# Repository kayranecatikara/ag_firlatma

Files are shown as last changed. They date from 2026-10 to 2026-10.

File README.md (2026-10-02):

# Ağ Fırlatma Mekanizması — Tasarım, Modelleme ve Doğrulama

Tail-sitter VTOL dronun altına monte edilen, **lastik bant tahrikli ağ
fırlatıcı**. Hedef: **X-UAV Talon** (1718 mm kanat açıklığı). İki araç da
**100 km/h** ile uçuyor.

**Öldürücü mekanizma pervaneye ip dolanmasıdır** — bilyeler ikincil
(12 g, 20 m/s'de 2.4 J: köpüğe çukur açar, yapı kırmaz). Tek bir ipin
pervaneye değmesi motoru durdurmaya yeter; bu, ağın göz açıklığını
belirleyen temel kriterdir.

> ⚠️ **Durum: üretime hazır, HENÜZ TEST EDİLMEDİ.** Modelin
> cevaplayamadığı üç soru var (§6) — yer testleri yapılmadan uçuşa
> geçilmemeli.

---

## 1. Nasıl geliştirildi — yöntem

**İki katmanlı modelleme.** Ucuz bir indirgenmiş model (ROM) ile tasarım
uzayı taranıyor, pahalı tam 3B model ile doğrulanıyor.
**ROM defalarca YANLIŞ tasarım kararı üretti** — "yay uygulanamaz",
"helisel yiv gereksiz" gibi sonuçların hepsi ROM artefaktıydı ve ancak tam
model + Monte Carlo ile yakalandı (§5).

**SciPy ile tasarım uzayı keşfi.** Sobol dizisiyle örnekleme,
`differential_evolution` ile optimizasyon, Spearman sıra korelasyonuyla
duyarlılık analizi.

**Ağ modeli.** Yığınsal parametre (lumped-parameter) yaklaşımı: ağ
düğümlere yığınlaştırılıyor, iplikler **yalnızca ÇEKME taşıyan**
viskoelastik elemanlar — basma kuvveti taşımıyorlar (tek taraflı kısıt).
Bu, uzay enkazı yakalama literatürünün standardı. Her elemana
**normal/teğet ayrışımlı silindir sürüklemesi** uygulanıyor
(Cd_n ≈ 1.1, Cd_t ≈ 0.03). Entegrasyon: velocity-Verlet, CFL zaman adımı.

**Parametrik CAD.** FreeCAD 0.19 headless (`freecadcmd`), OpenCascade
boolean işlemleri. Tüm geometri `v4_konfig.json`'dan türetiliyor.

**Gazebo Harmonic (gz-sim 8) + DART, ÖZEL C++ system plugin.**
Gazebo'nun kendi sürükleme eklentileri ipliği modelleyemiyor; iplik
gerilmesi ve aerodinamik `AgFizik.cc` içinde hesaplanıp `AddWorldForce`
ile uygulanıyor.

**HİBRİT DEVİR.** Ağın paketten açılması rijit-cisim temas problemi
değildir: paketli halde 709 çarpışma küresi 16 mm'lik hazneye tıkılıdır ve
DART'ın LCP çözücüsü yüz binlerce temas kısıtıyla çöker. Çözüm:
*paketten açılma* doğrulanmış Python modelinde, *temas ve yakalama*
Gazebo'da — ağ **t = 80 ms**'de açık halde devralınıyor.

**Tedarik araştırması.** Paralel web ajanlarıyla; her link açılıp sayfa
içeriğinden doğrulandı, doğrulanamayan link verilmedi (`TEDARIK_PLANI.md`).

### Kullanılan araçlar
`Python 3` · `NumPy` · `SciPy` · `matplotlib` · `FreeCAD 0.19` ·
`Gazebo Harmonic (gz-sim 8)` · `DART` · `C++17` · `gz-plugin2` · `CMake`

---

## 2. Doğrulama — projenin güven temeli

Python (kendi yazdığım velocity-Verlet entegratörü) ve Gazebo (DART)
**bağımsız iki çözücü** olarak aynı fiziği çözüyor:

| | Python | Gazebo | sapma |
|---|---|---|---|
| R_tepe | 1.126 m | 1.120 m | **−0.5 %** |
| zirve zamanı | 192 ms | 192 ms | **−0.2 %** |
| atış penceresi | 3.54 – 6.08 m | 3.54 – 6.04 m | **4 cm** |

Gerçek altıgen örgüde, devir sonrası serbest uçuşta sapma **%0.23**.

**Bağımsız bir teyit daha:** ürettiğim örgü **83.2 m** iplik veriyor,
`params.py`'daki analitik formül (`2A/göz + 6R`) **81.1 m** — **%2.5**
uyum. İki ayrı yoldan hesaplanan büyüklükler örtüşüyor.

---

## 3. Sonuçlar

```
çıkış hızı        : 31.1 m/s
açılma            : 200 ms'de R = 1.13 m      (gereken 0.859 m — Talon yarı açıklığı)
geometrik pencere : 3.56 – 6.54 m
EN İYİ TETİKLEME  : 4.0 – 4.5 m               (§5 — Gazebo bunu tersine çevirdi)
ip tepe yükü      : 19 N                      (kopan eleman: 0)
sistem kütlesi    : ~390 g
ağ                : Ø2.6 m altıgen dış hat, KARE göz 200 mm,
                    142 bağ, ~2.5 saat el emeği
```

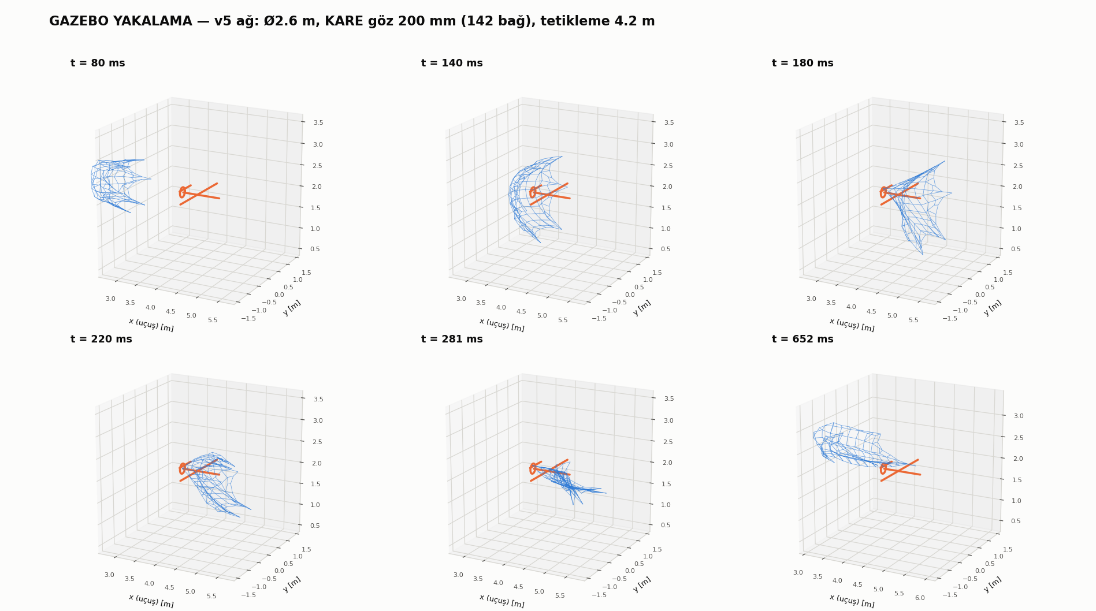
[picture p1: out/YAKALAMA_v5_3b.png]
Yakalama


### Tasarım tablosu

| | Değer |
|---|---|
| Namlu | Ø52 × **149.8 mm**, DÜZ delik (yiv yok), arkası açık (yükleme ağzı) |
| Tahrik | **4 × Ø15.2/4 mm saf lateks tüp**, **30.3 mm** kauçuk boyu, ×4.0 kurulu |
| Bant bağlantısı | ağız bileziği kulakları (±Z) → kapsüldeki **Ø8 civa çeliği** çapraz pim (düz yarıklardan çıkar) |
| Yuva koni açısı | **13°** |
| Bilye / ağ | Ø12.7 **kurşun** × 6 / **Ø2.6 m, KARE göz 200 mm** + çevre halatı, Dyneema **örgü** Ø0.165 |
| Strok | **91 mm** |
| v_çıkış | **31.1 m/s** |
| Atış penceresi | **3.56 – 6.54 m** geometrik · **EN İYİ 4.0–4.5 m** (bkz. §5) |
| Kütle | **~390 g** (servolar + ağ + bilyeler dahil) — MG996R ile 492 g idi |
| Tetik | 2 karşılıklı pim, kapaklı kartuş + geri-getirme yayı; **PTFE burç ŞART**; 2 × **MİKRO** metal dişli servo (~14 g), makara r=2.2 mm |

Yaylı tasarım `cad/eski_tasarimlar/yay_tahrikli/` altında arşivlendi (kısa namluda
blok boyu stroku yiyor, kurma kuvveti 1000 N'u aşıyordu).

Bant doğrulaması: tek banda bagaj kantarıyla ×3.0'da ~184 N, ×3.5'te ~217 N
beklenir (`agsim/lastik.py: cekme_testi_tablosu`). Ölçüm farklıysa `Gmod`'u
aynı oranda düzeltin.

---

## 4. Temel fizik

**Balistik uzunluk** λ = 2m/(ρ·Cd·A) — ağ menzilini belirleyen tek baskın
parametre. Kapalı form erişilebilir menzil:

```
Δx_max = λ·[ln(v₀/V) − 1 + V/v₀],     v₀ = V + v_namlu
```

**Ağı durduran sürüklemedir, gerilme değil.** Tepe iplik gerilmesi
serbest uçuşta 2–4 N, kopma yükü 64 N. Ağ gergin hale gelip durmuyor;
hava onu yavaşlatıyor.

**Ağ neden açıldıktan sonra kapanıyor?** Bilyeler radyal hızla dışa
açılıyor, ağ gerilince elastik olarak geri çekiyor; hava bu salınımı
sönümlüyor. İplik sönümlemesinin (ζ = 0.05…0.90) etkisi **sıfır** —
sönümleme tamamen aerodinamik.

**Ağır bilye hafif ağı çekiyor.** Bilye λ ≈ 234 m, ağ λ ≈ 0.24 m.

**Pervane yakalama kriteri.** Kenarı `a` olan kare hücreye sığan en büyük
çember `a√2`. Eskiden "diskte bir DÜĞÜM bulunsun" diyordum (göz < 163 mm);
tek ip motoru durdurmaya yettiği için gerçek kriter "diski en az bir İP
kessin" → **göz < 230 mm**. Göz 200 mm seçildi (%13 pay).
Gazebo ölçümü: ağ uçağın üzerinden süpürülürken diskten **32 farklı
iplik** geçiyor.

---

## 5. Yol boyunca düzeltilen hatalar

> Bu bölüm projenin en değerli kısmı. "Şunu yaptık, çalıştı" tarzı bir
> anlatım bu projeyi anlatmaz — doğru sonuçların çoğuna yanlış sonuçları
> yakalayarak varıldı.

### Fizik / model
- **Hava sürüklemesinin etkisini küçümsemiştim.** Kullanıcı itiraz etti,
  kontrol ettim: **HAKLIYDI.** Menzil vakumda 61.6 m, sürüklemeyle 4.0 m.
  Yaptığım karşılaştırma zaten ikisi de sürükleme-baskın iki durumu
  kıyaslıyordu, bu yüzden etki küçük görünüyordu.
- **"Helisel yiv gereksiz" bulgusu YANLIŞTI.** Enerjisi yetersiz yay ve
  yanlış amaç fonksiyonundan geliyordu; Pareto cephesinde 9 tasarımın
  8'i helisel yiv kullanıyordu.
- **"Yay uygulanamaz" sonucu ROM artefaktıydı.** Tam model Monte
  Carlo'da %93–98 yakalama verdi.
- **Amaç fonksiyonu yanlıştı** (R_eff). `differential_evolution`
  11.27 m'lik sahte bir optimum buldu; Monte Carlo o tasarımda **%0**
  yakalama verdi. Amaç fonksiyonu "angajman anındaki kapsama"ya çevrildi.
- **netfull'de sürükleme gerçek ağa ölçeklenmiyordu.** Kütle
  ölçekleniyordu ama sürükleme ölçeklenmiyordu → ağ sürüklemesi **~2.5×
  düşük** hesaplanıyordu. Bu düzeltmeden önceki tüm sayılar iyimserdi.
- **Kare-göz iplik formülü altıgen ağa uygulanmıştı.**

### Topoloji — en büyük düzeltme zinciri
- **Tasarım taraması "örümcek ağı" topolojisiyle yapılmıştı.** Gerçek
  altıgen örgü **%6.7 daha geniş** açılıyor. Sebep topolojik: örümcek
  ağındaki sürekli çevrel halkalar çember gerilmesiyle açılmaya direniyor,
  bal peteğinde sürekli halka yok.
- **ÇEVRE HALATI modellenmemişti** — malzeme listesinde (F2) vardı ama
  simülasyona girmemişti. Onsuz kare ağın köşeleri desteksiz kalıyor ve
  açılamıyordu; bu yüzden kare gözü yanlış değerlendirdim.
- **Düğüm sayısını 709 sandım; gerçek 315.** Malzeme listesindeki 259
  (göz kesişimi) doğruymuş. Kendi kurduğum altıgen kafesin düğümünü sayıp
  listeyi "düzeltmiştim".

### Operasyonel — Gazebo'nun tersine çevirdiği tavsiye
**"Pencerenin uzak yarısından ateşle, ip yükü düşük olur" demiştim. YANLIŞ.**

Python modeli yalnızca *"ağ yeterince açık mı"* diye bakıyor;
*yakalayıp yakalamadığına* bakmıyor. Gazebo'nun temas simülasyonu uzakta
ağın uçağın üzerinden **değip geçtiğini** gösterdi:

| tetikleme | ağın uçağa serilme oranı | aktarılan momentum |
|---|---|---|
| 3.6 m | %78 | 2.08 kg·m/s |
| **4.2 m** | %52 | 1.64 kg·m/s |
| 5.0 m | %28 | 0.64 kg·m/s |
| 7.0 m | **%24** | 0.37 kg·m/s |

**DOĞRUSU: 4.0 – 4.5 m'den ateşle.**

### Gazebo / yazılım
- **Ağ düğümlerinin pozları mutlak yazılıydı.** Entegrasyon risk analizinde
  yakalandı: fırlatıcı başka bir yere konduğunda ağ ondan kopuk, yanlış bir
  ofsette taşınıyordu — doğru yönde ama yanlış yerden çıkan, sessiz bir hata.
  Plugin'e `<uretim_firlatici_poz>` eklendi; ağ artık fırlatıcının gerçek
  pozuna taşınıyor.
- **Hedef link adı `govde` çok yaygındı.** Entegrasyon testinde plugin,
  test dronunun kendi gövdesini hedef sanıp üzerine trim kuvveti uyguladı.
  Hedef link `talon_govde` olarak yeniden adlandırıldı.
- **`WorldPoseCmd` kaldırma zamanlaması.** Kinematik taşımayı eklerken poz
  komutunu atıştan bir adım sonra kaldırıyordum; ateşleme adımında poz komutu
  ile hız komutu çakışıp **sahte gerilme sıçraması** yarattı (16 → 31 N).
  Entegrasyon testinde yakalandı; komut artık ateşleme adımında, hızlar
  verilmeden önce kaldırılıyor.
- **`SetLinearVelocity` kalıcı bir KİNEMATİK KISIT bırakıyor.**
  `LinearVelocityCmd` bileşeni her adımda yeniden uygulanıyor → gövdeler
  o hıza kilitleniyor ve hiçbir kuvvete tepki vermiyor. Serbest düşme
  testiyle kanıtlandı (hız −0.006 m/s'de sabit kaldı, −2.0 olmalıydı).
  Atıştan bir adım sonra komut kaldırılarak düzeltildi.
- **dt kararlı sınırın 4 katıydı** (0.5 ms, sınır 0.12 ms) → sayısal
  patlama, ODE AABB taşması. Artık dt iplik periyodundan otomatik
  türetiliyor.
- **Kuvvet tavanı 5 N çarpma anında 10486 kez devreye girip fiziği
  bozuyordu.** 200 N'a çekildi (yalnızca NaN koruması); yerine iplik
  kopma sayacı eklendi.
- **SDF üreticisinde tanımsız sabit** (`PERVANE`) → üretim sessizce
  çöktü ve **4 Gazebo koşusu ESKİ dünya dosyasını** simüle etti.
  Dördünün de birebir aynı sayıyı vermesi fark ettirdi. Üretici hatası
  artık koşuyu durduruyor.
- **Hazne hacmi eski Python değerinden alınmıştı** (20.5 cm³);
  CAD'deki gerçek değer **17.3 cm³**.

### CAD
- v1'de durdurma omzu bilyeleri engelliyordu (omuz iç çapı 18.7 mm,
  bilye dış kenarı 19.9 mm).
- Kama/oluk profilinin eksenleri ters girilmişti (radyal ↔ çevrel).
- Pim kapsüle teğetti → geçersiz katı; profil 0.8 mm gömüldü.
- **Tetik tek geçme çubuktu.** Kullanıcı asimetrik çekiş itirazı yaptı:
  **HAKLIYDI.** İki ayrı pime bölündü.

### Namlu kısaltma — menzil beklenenden az etkilendi
Namlu 180.5 → **149.8 mm**'ye indirildi (strok 114 → 91 mm).

| namlu | strok | enerji | v_çıkış | pencere |
|---|---|---|---|---|
| 180.5 mm | 114 mm | 78.2 J | 34.6 m/s | 3.58 – 6.80 m |
| **149.8 mm** | **91 mm** | **62.4 J** | **31.1 m/s** | **3.56 – 6.54 m** |
| 140 mm | 84 mm | 57.3 J | 29.9 m/s | 3.56 – 6.46 m |

Çıkış hızından **%10** verildi ama pencerenin uzak kenarı sadece **26 cm**
kısaldı. Sebep §4'teki balistik uzunluk: ağı durduran sürüklemedir ve
`Δx ∝ λ·[ln(v₀/V) − 1 + V/v₀]` — **logaritmik**, hıza doymuş davranır.
Kazanç: namlu −31 mm, **−20 g**, filament 210 → 190 g.
Kurma kuvveti **değişmedi** (30.6 kg/bant) çünkü λ=4.0 korundu; sadece
bant daha kısa kesiliyor (38 → 30.3 mm).

Gazebo ile doğrulandı (tetikleme 4.2 m): tepe iplik yükü **16.4 N**,
kopan eleman **0**, pervaneden geçen **14 iplik**, ağın uçağa serilme
oranı **%47**, aktarılan momentum **1.30 kg·m/s**. Yakalama 180 mm'ye
göre bir miktar zayıfladı (53 → 14 iplik, momentum 1.64 → 1.30) ama
"tek ip yeter" kriterinin **14 katı** üzerinde.

### Tedarik — araştırmanın değiştirdiği tasarım kararları
- **7075-T6 Ø8 Türkiye'de SATILMIYOR** (çekme 7075 Ø13'ten başlıyor).
  Mukavemet hesabı yapıldı: tasarım gerilmesi **202 MPa**.

  | malzeme | SF | karar |
  |---|---|---|
  | 7075-T6 *(hedef)* | 2.4× | TR'de yok |
  | **civa çeliği 1.2210** | **2.2×** | ✅ seçildi |
  | 6061-T6 | 1.4× | sınırda |
  | 6063 | **0.84×** | ❌ kırılır |
  | 304 paslanmaz | **1.04×** | ❌ yetersiz |

  Bedeli: +23 g (sistem 469 → 492 g).
- **TR'deki MG996R'lerin hepsi "half metal"** (iç dişliler plastik).
  Pahalı servo almak yerine makara küçültüldü — ama asıl düzeltme aşağıda.
- **MG996R çok ağırdı (110 g = sistemin %22'si).** Servo seçimini
  **iş korunumunu** gözden kaçırarak yapmıştım: `tork × açı = F_pim × strok`
  sabittir ve r=4 mm makara servonun dönüş aralığının yalnızca **86°**'sini
  kullanıyordu. Makara r=2.2 mm + kanal derinliği 5→4 mm ile **130°**
  kullanılıyor, gereken tork **3.9 → 2.15 kg·cm**'ye düşüyor.
  Sonuç: 2 × MG996R (110 g) yerine 2 × mikro metal dişli servo (28 g),
  **1.81× pay** ve **−82 g**. Namlunun servo yatağı zaten M2/mikro servo
  için tasarlanmıştı; sadece delik aralığı 18 → 28 mm'ye düzeltildi (oval,
  marka farkını tolere etsin diye).

### Üç ayrı yerde kullanıcının fiziksel sezgisi analizi yendi
1. **Sürükleme büyüklüğü** — "bu etki çok daha fazla olmalı" dedi, haklıydı.
2. **Tek pim asimetrisi** — "kapsül pimin çekildiği tarafa kayar" dedi,
   haklıydı; tasarım iki pime bölündü.
3. **Ağın gereğinden karmaşık olması** — "bu kadar ipe ve düğüme gerek yok,
   tek ip pervaneye yeter" dedi. Doğrulandı: bağ 811 → 142, iplik
   100 → 53 m, üstelik **pencere uzadı ve yakalama iyileşti**.

---

## 6. Modelin cevaplayamadıkları

Dürüst olmak gerekirse üç soru açık. Üçü de yer testiyle çözülecek.

**1. AĞIN DOLANMASI — en kritik belirsizlik.**
İpin ipe takılması rijit-cisim + LCP çözücüsüyle modellenemez; ip/kumaş
çözücüsü (Cosserat çubuk veya konum-tabanlı dinamik) gerekir. Ağ paketten
temiz açılacak mı, bunu **yalnızca yer testi** söyler (240 fps çekim,
`URETIM_MONTAJ_REHBERI.md` §T3). Üç temiz açılma görülmeden uçuşa
geçilmemeli.

**2. PERVANENİN İPİ KESME EŞİĞİ.**
Eğilim biliniyor (temas basıncı ∝ 1/d), **mutlak eşik bilinmiyor**.
Kullandığım enine dayanım verisi gerçek kesilme kriterini yakalamıyor.
Tezgâh testi gerekiyor (§T5): ipi kanada sar, ~15 N ger, motoru çalıştır.

**3. DÜĞÜM VERİMİ.**
%55 literatür tahmini (UHMWPE aralığı %50–60). Gerçek düğümlü numuneyle
çekme testi yapılmalı. *(Yükler düşük olduğu için belirleyici değil —
hiçbir eleman kapasitenin yarısına ulaşmıyor.)*

**Ayrıca: TARET TASARIMI henüz yapılmadı** (kullanıcı isteğiyle ertelendi).
Şimdilik sabit bir yatak yeterli.

---

## 7. Dosya haritası

```
baski/                  ★ 3D BASKI — doğrudan slicer'a at
                          8 × STL (BASKI YÖNÜNDE hazır, tablaya oturtulmuş,
                          döndürme gerekmez) + 8 × STEP + BASKI_AYARLARI.md
baski.zip                 aynısının zip'i

ALISVERIS.md            ★ ALIŞVERİŞE GİDERKEN BUNU AL — tek dosya,
                          siparişe göre gruplu, 42 kutucuk
URETIM_MONTAJ_REHBERI.md  üretim + montaj, 14 bölüm (güvenlik, baskı,
                          ağ örme, bant, montaj, kurma, testler)
malzeme_listesi.md        teknik özellikler, her parçanın nereye gittiği
TEDARIK_PLANI.md          doğrulanmış satın alma linkleri
SATIN_ALMA_LISTESI.md     kategori bazlı alışveriş rehberi
TORNA_IS_EMRI.png         tornacıya götürülecek ölçülü teknik resim

agsim/                    fizik modeli
  params.py                 parametreler, malzeme veritabanı
  netfull.py              ★ tam 3B ağ modeli (karar veren model)
  hexag.py                ★ gerçek örgü üreteci (altıgen + kare + çevre halatı)
  lastik.py               ★ lateks bant modeli (neo-Hooke)
  kesilme.py              ★ pervane kesme analizi (Smith, bükülme, düğüm)
  aero.py                   sürükleme
  netrom.py, dse.py, ...    ROM ve tarama altyapısı (arşiv)

cad/
  lastik_montaj_v4.py     ★ parametrik tam montaj (v4_konfig.json'dan)
  baski_parcalari.py      ★ baskı parçalarını üretir → baski/
  ciz_torna_resmi.py        torna iş emri çizimi
  eski_tasarimlar/          arşiv (.py kaynaklar; .step'ler üretilebilir)

gazebo/
  models/ag_firlatici/    ★ MONTE EDİLEBİLİR MODEL PAKETİ (bkz. §9)
                            model.config + model.sdf + meshes/
                            4 link, 389 g, montaj çerçeveleri
  plugin/AgFizik.cc       ★ özel C++ system plugin (ağ fiziği + tetik topic'i)
  scripts/ag_sdf_uret.py  ★ dünya üreteci
  scripts/model_paketi_uret.py  model paketini üretir
  worlds/ag_atis.sdf        ÜRETİLMİŞ test dünyası (monte edilecek model DEĞİL)
  worlds/ag_eklentisi.sdf ★ ÜRETİLMİŞ — kendi dünyana yapıştırılacak
                            ağ + plugin parçası (§9.2)
  scripts/karsilastir.py    Gazebo ↔ Python doğrulaması
  scripts/ciz_yakalama.py   3B yakalama görselleştirmesi
  kos.sh                    koşu betiği

out/                      grafikler, sonuç belgeleri, konfigürasyonlar
  GAZEBO_sonuc.md           Gazebo entegrasyonu sonuçları
  AG_v5_SADELESTIRME.md     ağ sadeleştirme kararı
  IP_CAPI_KARAR.md          iplik çapı kararı
arsiv_analizler/          süperseded analizler (OKUBENI.txt uyarısıyla)
```

**Nereden başlamalı:** üretecekseniz `ALISVERIS.md` → `baski/` →
`URETIM_MONTAJ_REHBERI.md`. Modeli anlamak istiyorsanız §5 (hatalar) →
`agsim/netfull.py` → `out/GAZEBO_sonuc.md`.
**Kendi dronuna entegre edecekseniz doğrudan §9.**

---

## 8. Nasıl çalıştırılır

```bash
# --- Python analizleri ---
python3 run_menzil_nihai.py        # menzil, atış penceresi, Monte Carlo
python3 run_ip_incelt.py           # iplik çapı taraması
python3 ciz_ag_2b.py               # ağ topolojisi karşılaştırma çizimi

# --- CAD ---
freecadcmd cad/lastik_montaj_v4.py # tam montaj → cad/V4_*.step
freecadcmd cad/baski_parcalari.py  # baskı parçaları → baski/ (STL + STEP)

# --- Gazebo plugin derleme ---
cd gazebo/plugin && mkdir -p build && cd build
cmake .. -DCMAKE_BUILD_TYPE=Release && make -j4

# --- Simülasyon ---
./gazebo/kos.sh dogrulama          # hızlı, hedefsiz, Python ile karşılaştırma
AG_ORGU=kare ./gazebo/kos.sh yakalama       # gerçek örgü + hedef
AG_ORGU=kare ./gazebo/kos.sh yakalama gui   # üstüne GUI

python3 gazebo/scripts/karsilastir.py       # Gazebo ↔ Python doğrulaması

# --- Monte edilebilir model paketi + harici tetikle atış (bkz. §9) ---
python3 gazebo/scripts/model_paketi_uret.py        # gazebo/models/ag_firlatici/
export GZ_SIM_RESOURCE_PATH=$PWD/gazebo/models
AG_FIRLATICI=1 AG_TETIK=harici AG_ORGU=kare AG_RAG=1.3 AG_GOZ=0.20 \
  python3 gazebo/scripts/ag_sdf_uret.py
gz sim -r gazebo/worlds/ag_atis.sdf &
gz topic -t /ag_firlatici/ates -m gz.msgs.Boolean -p "data: true"
```

### Ortam değişkenleri

| Değişken | Varsayılan | Ne yapar |
|---|---|---|
| `AG_ORGU` | `orumcek` | örgü tipi: `orumcek` \| `hex` \| `kare` |
| `AG_RAG` | config | ağ köşe yarıçapı [m] |
| `AG_GOZ` | config | göz açıklığı [m] |
| `AG_DIP` | config | iplik çapı [m] |
| `AG_MENZIL` | `4.65` | hedefin atış anındaki mesafesi [m] |
| `AG_CARPISMA` | `1` | `0` = çarpışma/hedef yok (hızlı doğrulama) |
| `AG_DEVIR` | hex/kare için `0.08` | hibrit devir anı [s]; `0` = kapsülden fırlat |
| `AG_SURE` | `0.75` | simüle edilecek sim-zamanı [s] |

### Gereksinimler
```
Python 3.8+ · numpy · scipy · matplotlib
FreeCAD 0.19+          (freecadcmd)
Gazebo Harmonic        (gz-sim 8) + gz-physics (DART)
gz-cmake3, gz-plugin2, gz-math7, gz-common5, sdformat14, CMake 3.16+
```

---

## 9. Başka bir araca entegrasyon

> Bu bölüm, fırlatıcıyı **kendi drone modeline** eklemek isteyenler için.
> `gazebo/worlds/ag_atis.sdf` bir **test dünyasıdır**, monte edilebilir model
> değildir — onu kullanma. Monte edilecek paket: `gazebo/models/ag_firlatici/`

### 9.1 Model paketi

```
gazebo/models/ag_firlatici/
  model.config          paket tanımı, kütle dağılımı, açıklama
  model.sdf             4 link + 3 eklem + 2 montaj çerçevesi
  meshes/namlu.stl      görsel (çarpışma = silindir, daha hızlı)
  meshes/kapsul.stl
```

**Eksen düzeni:** `+X` namlu ekseni (ağız yönü), `+Z` yukarı.
**Orijin:** namlunun **arka yüzünün merkezi** (yükleme ağzı).

| link | kütle | içerik |
|---|---|---|
| `namlu` | **216.2 g** | gövde + 4 lateks bant + tetik donanımı + kablolar |
| `kapsul` | **138.0 g** | kapsül + çapraz pim + **ağ + 6 kurşun bilye** |
| `servo_sag` / `servo_sol` | **14.3 g** ×2 | mikro metal dişli servo |
| **TOPLAM** | **389.4 g** | |

`kapsul` link'i `namlu`ya **prizmatik eklemle** bağlı (eksen +X, strok 0–91 mm).
Servolar sabit eklemle. Atalet tensörleri gerçek geometriden hesaplandı
(içi boş silindir / kutu).

İki montaj çerçevesi var:
- **`montaj`** — namlu ortası, üst yüzey. Kendi gövdene bağlarken bunu referans al.
- **`agiz`** — namlu ucu. **Tetikleme mesafesi buradan ölçülür.**

### 9.2 ⚠️ İKİ PARÇA GEREKİYOR — tek `<include>` yetmez

Bu en sık yapılacak hata, baştan söyleyeyim:

| | ne içerir | `<include>` ile gelir mi? |
|---|---|---|
| **1. Model paketi** `ag_firlatici` | namlu + kapsül + servolar, 389 g, montaj çerçeveleri | ✅ evet |
| **2. Ağ eklentisi** `ag_eklentisi.sdf` | **142 ağ düğümü + AgFizik plugin'i** | ❌ **HAYIR — elle yapıştır** |

**Model paketinin içinde ağ da plugin de YOKTUR** (`model.sdf`'te 0 plugin,
0 düğüm). Sadece `<include>` yaparsan: doğru kütleli, doğru görünen, ama
**hiç ateş etmeyen** bir namlu elde edersin.

Sebebi §9.6'daki ilk madde: ağ düğümlerinin her biri **ayrı `<model>`**
olmak zorunda, bu yüzden fırlatıcı modelinin *içine* konamıyorlar.

Üreteç ikinci parçayı **yapıştırmaya hazır** olarak yazıyor:
```
gazebo/worlds/ag_eklentisi.sdf    <- bunu kendi <world>'üne kopyala
```

### 9.2.1 Kendi dünyana ekleme — kopyala-yapıştır

```bash
# gz sim modeli bulsun diye:
export GZ_SIM_RESOURCE_PATH=$GZ_SIM_RESOURCE_PATH:/yol/ag_firlatma/gazebo/models
# gz sdf -k ile DOGRULAMA yapacaksan AYRICA (farkli degisken!):
export SDF_PATH=$SDF_PATH:/yol/ag_firlatma/gazebo/models
```

> ⚠️ `<include>` ve `<joint>` **DÜNYA SEVİYESİNDE** olmalı — `<model>`
> etiketinin *içine* koyup `firlatici::namlu`ya joint atarsan SDF çözemez
> (`child frame ... not found`). Aşağıdaki biçim doğrulandı.

```xml
<world name="benim_dunyam">

  <model name="benim_dronum">
    <link name="govde"> ... </link>
  </model>

  <!-- 1. PARCA: FIRLATICI MODELI — dünya seviyesinde -->
  <include>
    <uri>model://ag_firlatici</uri>
    <name>firlatici</name>
    <pose>0 0 2.0 0 0 0</pose>
  </include>

  <!-- Dünya seviyesinde sabit eklemle gövdene bağla -->
  <joint name="firlatici_baglanti" type="fixed">
    <parent>benim_dronum::govde</parent>
    <child>firlatici::namlu</child>
  </joint>

  <!-- 2. PARCA: ag_eklentisi.sdf içeriğini BURAYA yapıştır (§9.3) -->

</world>
```

Tail-sitter'da namlu **ileri-aşağı** bakmalı; `<pose>`'un son üç değeriyle
(roll pitch yaw) eğ.

### 9.3 Ağ fiziği — model paketinde DEĞİLDİR

Ağ düğümleri **ayrı `<model>`'ler** olarak üretilir ve dünya seviyesindeki
`AgFizik` plugin'i ile çözülür. Bu kasıtlı — §9.6'daki ilk maddeye bak.

```bash
# plugin derle
cd gazebo/plugin && mkdir -p build && cd build
cmake .. -DCMAKE_BUILD_TYPE=Release && make -j4
export GZ_SIM_SYSTEM_PLUGIN_PATH=/yol/ag_firlatma/gazebo/plugin/build

# ag + plugin blogunu uret (kendi dunyana kopyalayacagin parca)
AG_FIRLATICI=1 AG_TETIK=harici AG_ORGU=kare AG_RAG=1.3 AG_GOZ=0.20 \
  python3 gazebo/scripts/ag_sdf_uret.py
```

Üreteç **`gazebo/worlds/ag_eklentisi.sdf`** dosyasını yazar — içinde yalnızca
ağ düğümleri + `<plugin>` bloğu vardır, başlığında ne yapılacağı yazılıdır.
**Tamamını** kendi `<world>` etiketinin içine yapıştır. Plugin'de şu iki alanı
kendi modeline göre ayarla:

```xml
<plugin filename="AgFizik" name="ag::AgFizik">
  <firlatici_link>namlu</firlatici_link>      <!-- taşıyıcı link adı -->
  <tetik_konu>/ag_firlatici/ates</tetik_konu>
  <firlatma_t>-1</firlatma_t>                 <!-- -1 = yalnızca harici tetik -->
  ...
</plugin>
```

`<firlatici_link>` verilince plugin:
- atıştan **önce** ağ düğümlerini o linke **kinematik olarak taşır**
  (drone uçarken ağ onunla gider),
- atış anında hızları linkin **o anki yönelimine** göre uygular ve
  **linkin kendi hızını ekler**.

`<uretim_firlatici_poz>` ise ağı **fırlatıcının gerçek pozuna taşır.**
Ağ düğümlerinin pozları SDF'te *mutlak* yazılıdır ve üretim anındaki
varsayılan fırlatıcı pozunu temel alır; bu alan sayesinde plugin farkı
hesaplayıp ağı doğru yere kaydırır. **Yani fırlatıcıyı dünyada istediğin
yere ve açıya koyabilirsin** — üreteci yeniden çalıştırman gerekmez.

Doğrulandı: fırlatıcı `(3.0, 1.5, 2.0)` + 0.5 rad yaw'a konduğunda plugin
`ag, firlaticinin GERCEK pozuna tasiniyor (uretim -0.1498 0 2 -> gercek
3 1.5 2)` diyerek ağı taşıdı ve atış normal çalıştı (R_tepe 1.08 m).

### 9.3.1 ⚠️ `<physics>` AYARINI DA TAŞI — en sinsi hata

`ag_eklentisi.sdf` **ağ ve plugin'i** taşır ama `<physics>` bloğunu
**taşımaz**. Kendi dünyanın `<max_step_size>` değeri ne ise o kullanılır.

Gazebo'nun varsayılanı **1 ms**; bu tasarımın gerektirdiği **34 µs**'nin
**29 katı**.

**Ölçüldü — ve çökmekten daha kötüsü oluyor:**

| | doğru dt (34 µs) | yanlış dt (1 ms) |
|---|---|---|
| ağ açılması R_tepe | **1.08 m** | **0.57 m** |
| tepe iplik yükü | 16.4 N | 9.6 N |
| çökme / NaN | — | **YOK** |

Ağ, gereken **0.859 m**'nin *altında* açılıyor ve simülasyon hiç hata
vermiyor. Yani "bu ağ Talon'u yakalayamıyor" gibi **tamamen yanlış bir
sonuca** varır ve ona inanırsın. Çökseydi fark ederdin.

> Daha ince örgülerde (709 düğümlü hex) aynı hata **gerçekten çökertiyor**:
> ODE AABB taşması (`aabbBound >= dMinIntExact` assertion). Yani belirti
> örgüye göre değişiyor — ama ikisi de yanlış.

```xml
<physics name="ag_icin" type="dart">
  <max_step_size>0.000034</max_step_size>   <!-- üretecin yazdığı değer -->
  <real_time_factor>0</real_time_factor>
</physics>
```

Üreteç doğru değeri her koşuda ekrana yazar (`dt = 34 us`) ve
`ag_eklentisi.sdf` başlığına da koyar. **Kendi dünyanda bu değeri kullan.**

> Bu, dronun geri kalanı için gereksiz yere küçük bir adım. Ağ fiziği
> gerçekten bunu istiyor; ağı simüle etmediğin koşularda eklentiyi çıkarıp
> normal dt'ye dönebilirsin.

### 9.3.2 Entegrasyon kontrol listesi

- [ ] `GZ_SIM_RESOURCE_PATH` → `gazebo/models` (gz sim modeli bulsun)
- [ ] `SDF_PATH` → `gazebo/models` (`gz sdf -k` ile doğrulayacaksan)
- [ ] `GZ_SIM_SYSTEM_PLUGIN_PATH` → `gazebo/plugin/build`
- [ ] `<include>` ve `<joint>` **dünya seviyesinde** (model içinde değil)
- [ ] **`ag_eklentisi.sdf` içeriği `<world>` içine yapıştırıldı**
- [ ] `<firlatici_link>` kendi taşıyıcı link adınla eşleşiyor
- [ ] Kendi aracının hiçbir linki `<hedef_ad>` (`talon_govde`) ile aynı adda değil
- [ ] Kendi aracının hiçbir modeli `m_dugum_*` adını kullanmıyor
- [ ] **`<max_step_size>` = 0.000034** (üretecin yazdığı değer; varsayılan 1 ms PATLAR)
- [ ] `gz sdf -k dunyam.sdf` → **"Valid."**

### 9.4 Ateşleme

```bash
gz topic -t /ag_firlatici/ates -m gz.msgs.Boolean -p "data: true"
```

Kendi kontrolcünden `gz-transport` ile de yayınlayabilirsin:

```cpp
gz::transport::Node node;
auto pub = node.Advertise<gz::msgs::Boolean>("/ag_firlatici/ates");
gz::msgs::Boolean m; m.set_data(true); pub.Publish(m);
```

### 9.5 Ortam değişkenleri

| Değişken | Varsayılan | Ne yapar |
|---|---|---|
| `AG_FIRLATICI` | `0` | `1` = fırlatıcı modelini dünyaya ekle, ağı ağzında doğur |
| `AG_TETIK` | `zamanli` | `harici` = yalnızca topic ile ateşle |
| `AG_TETIK_KONU` | `/ag_firlatici/ates` | tetik topic adı |
| `AG_HEDEF` | `1` | `0` = Talon hedefini koyma |
| `AG_CARPISMA` | `1` | `0` = çarpışma geometrisi yok (hızlı doğrulama) |
| `AG_ORGU` | `orumcek` | `kare` (üretilecek tasarım) \| `hex` \| `orumcek` |
| `AG_RAG` / `AG_GOZ` / `AG_DIP` | config | ağ yarıçapı / göz açıklığı / iplik çapı [m] |
| `AG_MENZIL` | `4.65` | hedefin atış anındaki mesafesi [m] |
| `AG_DEVIR` | hex/kare: `0.08` | hibrit devir anı [s] — §9.6 |
| `AG_SURE` | `0.75` | simüle edilecek sim-zamanı [s] |

### 9.6 ⚠️ ENTEGRASYONDA DİKKAT — bunlar olmadan çalışmaz

**1. Her ağ düğümü AYRI `<model>` olmak ZORUNDA.**
Tek model içindeki eklemsiz linkleri gz-physics/DART **tek gövdeye kaynaklar**
ve hiçbiri hareket etmez. Bu yüzden ağ, fırlatıcı modelinin *içinde* değil,
dünya seviyesinde ayrı modeller olarak duruyor.

**2. Zaman adımı iplik periyodundan TÜRETİLMELİ.**
```
dt ≤ (1/15) · 2π·√(m_düğüm / k_eleman)
```
Üreteç bunu otomatik hesaplıyor; mevcut tasarımda **34 µs**.
`<max_step_size>`'ı elle büyütme — belirtisi örgüye göre değişiyor:
ince örgüde **ODE AABB taşması** (`aabbBound >= dMinIntExact` assertion),
kaba örgüde **sessizce yanlış sonuç** (§9.3.1'deki ölçüm). İkincisi daha
tehlikeli, çünkü fark etmezsin.

**3. Paketten açılma rijit-cisim çözücüyle YAPILAMAZ → hibrit devir ZORUNLU.**
Paketli halde 709 çarpışma küresi 16 mm'lik hazneye tıkılıdır; DART'ın LCP
çözücüsü yüz binlerce temas kısıtıyla **çöker**. Bu yüzden paketten açılma
doğrulanmış Python modelinde yapılır, Gazebo ağı **t = 80 ms**'de açık halde
devralır (`AG_DEVIR`). `AG_DEVIR=0` yapma.

**4. Geri tepme ~2.3 kg·m/s.**
Ağ + bilyeler 74 g, çıkış 31.1 m/s. Kapsül namlu içinde kalır, yani dışarı
atılan momentum bu. 2 kg'lık bir drone için **~1.2 m/s** hız değişimi —
tail-sitter'da tek atış yapılıp inileceği için nişan kayması önemsiz, ama
uçuş kontrolcüsü bunu bir bozucu olarak görecek.

**5. Tetikleme mesafesi 4.0–4.5 m.**
Geometrik pencere 3.56–6.54 m ama **uzakta ağ uçağın üzerinden değip geçiyor**
(7.0 m'de ağın yalnızca %24'ü uçağa değiyor). Servo gecikmesi ~120 ms;
100 km/h'te bu 0.77 m, yani hedef **5.0 m**'deyken tetikle.

### 9.7 ⚠️ BİLİNEN TUZAKLAR — aynı hatalara düşme

**`SetLinearVelocity` KALICI KİNEMATİK KISIT bırakır.**
`LinearVelocityCmd` bileşeni fizik sistemi tarafından **her adımda yeniden
uygulanır** → gövde o hıza kilitlenir ve hiçbir kuvvete tepki vermez. Serbest
düşme testiyle yakaladık: hız −0.006 m/s'de sabit kaldı, −2.0 olmalıydı.
Aynısı **`WorldPoseCmd`** için de geçerli (kinematik taşımada kullanılıyor).
Kendi kodunda hız/poz komutu kullanırsan **sen de kaldırmalısın**.

> **Kaldırma ZAMANLAMASI da önemli.** `WorldPoseCmd`'yi atıştan *bir adım
> sonra* kaldırınca, ateşleme adımında poz komutu ile `SetLinearVelocity`
> **aynı adımda çakışıyor**: düğümler önce poza kilitleniyor, sonra serbest
> kalıyor ve ağ sahte bir gerilme sıçraması yaşıyor. Entegrasyon testinde
> ölçüldü: **tepe gerilme 16 → 31 N**. Poz komutu ateşleme adımında,
> hızlar verilmeden **önce** kaldırılmalı. Plugin artık böyle yapıyor.

**Ağın DOLANMASI modellenmiyor.**
İpin ipe takılması rijit-cisim + LCP ile çözülemez; ip/kumaş çözücüsü
(Cosserat çubuk veya konum-tabanlı dinamik) gerekir. Simülasyon ağın temiz
açıldığını **varsayar**. Bu projenin en kritik doğrulanmamış varsayımı;
yer testiyle çözülecek.

**`<hedef_ad>` İSİM ÇAKIŞMASI.**
Plugin hedefi **link adıyla arayarak** bulur. Kendi aracının bir linki aynı
ada sahipse **plugin onu hedef sanar** ve üzerine seyir trim kuvveti (m·g)
uygular — yani dronunu havalandırır. Entegrasyon testinde tam olarak bu oldu:
hedef adı `govde` idi, test dronunun gövdesi de `govde`. Hedef link artık
`talon_govde` olarak adlandırılıyor. **Hedef istemiyorsan `AG_HEDEF=0`
kullan veya `<hedef_ad>` alanını boş bırak.**

**Pervane SABİT DİSK.**
Dönerek ipi sarma modellenmiyor. Plugin yalnızca diskten **kaç iplik geçtiğini**
sayar (`n_perv_toplam`). Asıl kilitleme mekanizması olan sarılma simülasyonun
dışında.

**Çalışma koşulu doğrulandı:** gz-sim 8 (Harmonic), DART, gz-plugin2,
gz-math7, gz-common5, gz-transport13, gz-msgs10, sdformat14, CMake 3.16+.

---

## 10. Model sınırları

- Ağ–ağ ve ağ–hava etkileşiminde ipin ipe takılması **modellenmiyor** (§6).
- Pervane Gazebo'da **sabit disk**; dönerek sarma modellenmiyor.
- Lateks için neo-Hooke modeli; sürünme (creep) ve histerezis yaklaşık.
- Monte Carlo hücre başına tek koşu — temas kaotik, saçılma ±%30 ölçüldü.
- Nişan hassasiyeti bilinmiyor; ağ yarıçapı fazlası nişan payıdır
  (R_açık 1.14 m, gereken 0.859 m → **0.28 m** tolerans).

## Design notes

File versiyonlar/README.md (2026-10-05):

# VERSİYONLAR

Her klasör, tasarımın o andaki halini **birebir yeniden üretecek** şekilde
dondurulmuştur: konfig dosyaları, CAD ölçü/hacimleri, basılacak STL+STEP'ler
ve ilgili dokümanlar.

> ⚠️ **Depo kökündeki `baski/` ve `AG_FIRLATICI_STL.zip` her zaman EN SON
> tasarımı taşır.** Belirli bir versiyonu basacaksan o versiyonun kendi
> `baski/` klasörünü kullan.

| Versiyon | Namlu | Strok | Bant L0 | Koni | Kapsül | R_pitch | Kapsülü durduran | Mesafe\* | Durum |
|---|---|---|---|---|---|---|---|---|---|
| [v1](v1/SURUM.md) | 149.8 mm | 91 mm | 30.3 mm | 40° | 45 mm | 15.5 | çapraz pim, 96 mm² | 0.80–0.98 m | ilk test |
| [v1.1](v1.1/SURUM.md) | 149.8 mm | 91 mm | 30.3 mm | 40° | 45 mm | **12.0** | **omuz, 303 mm²** | 0.79–0.97 m | basıldı |
| [v1.2](v1.2/SURUM.md) | 149.8 mm | 91 mm | 30.3 mm | 40° | 45 mm | 12.0 | omuz, 270 mm² | 0.79–0.97 m | basıldı |
| [v1.3](v1.3/SURUM.md) | 149.8 mm | 91 mm | 30.3 mm | 40° | 45 mm | 12.0 | omuz, 282 mm² | 0.78–0.97 m | ağ çıkamıyordu |
| [v1.4](v1.4/SURUM.md) | 149.8 mm | 91 mm | 30.3 mm | 40° | 45 mm | 12.0 | omuz, 282 mm² | 0.73–0.95 m | ağ namluda |
| [v1.5](v1.5/SURUM.md) | 149.8 mm | 91 mm | 30.3 mm | 40° | 45 mm | 12.0 / 13.4 | omuz, 282 mm² | 0.73–0.97 m | ağ geçişi Ø10.8 — yetersiz |
| [v2.0](v2.0/SURUM.md) | 149.8 mm | 91 mm | 30.3 mm | 40° | 45 mm | 18.2 | omuz, 300 mm² | 0.62–0.90 m | merkez hâlâ dar |
| [v2.1](v2.1/SURUM.md) | 149.8 mm | 91 mm | 30.3 mm | 40° | 45 mm | **22.0** | takoz, 304 mm² | 0.72–0.94 m | merkez ok, takoz bandı engelledi |
| [v2.2](v2.2/SURUM.md) | 149.8 mm | 91 mm | **34.3 mm** | 40° | 45 mm | **23.0** | omuz, 295 mm² | 0.50–0.84 m | namlu Ø55→**Ø64** |
| [v2.3](v2.3/SURUM.md) | 149.8 mm | 91 mm | 34.3 mm | 40° | 45 mm | 23.0 | omuz, 295 mm² | 0.50–0.84 m | takoz kaldırıldı |
| [v2.4](v2.4/SURUM.md) | 149.8 mm | 91 mm | 34.3 mm | 40° | 45 mm | 23.0 | omuz, 295 mm² | 0.50–0.84 m | yuva derinliği 9.0, başlık 11.0 |
| [**v2.5**](v2.5/SURUM.md) | 149.8 mm | 91 mm | 34.3 mm | 40° | 45 mm | 23.0 | **alt: tampon 7.6 J<br>üst: omuz 12.3 J** | 0.50–0.84 m | **güncel — kapsül 2 blok** |
| [v2](v2/SURUM.md) | 255.2 mm | 170 mm | 56.7 mm | 35° | 70 mm | 15.5 | çapraz pim, 96 mm² | 1.13–1.34 m | beklemede |

\* v2.2'den itibaren **ölçülmüş** bant ile (G·A0 = 54.7 N, dijital kantar,
50 mm numune +20/+40/+60 mm → 5.685/8.350/11.070 kg). Öncesi Gmod 0.45 MPa
varsayımı. 2 bant, L0 34.3 mm, λ 3.65 → **391 N (40 kg) kurma**, 17.4 m/s.

Ortak: ağ Ø2.2 m · kare göz 220 mm · Dyneema Ø0.60 mm · 6 × **Ø8.80 mm**
kurşun boncuk (24 g, kumpasla ölçüldü) · namlu iç çap **Ø64.0** (v2.2'den önce Ø55.0, v2.0'dan önce Ø43.4) · bant **Ø13.59** · bant ankrajı
Ø14 delik + delen pim.

## Neler değişti

**v1 → v1.1 — durdurma omuzu.** Kapsül namludan çıkmıyor, namlu içinde durması
gerekiyor: 47 g'ı 23 m/s'den durdurmak **12.8 J** demek. v1'de bunu sadece
Ø8 çapraz pimin yarık ucuna çarpması karşılıyordu (96 mm², 4.800 N) — tam
gerdirilirse yarık ucu kırılırdı. Namlu ağzına içe doğru omuz kondu; ama bu
ancak **boncuk çemberi 15.5 → 12.0 mm'ye çekilince** anlamlı oluyor (omuza yer
açılıyor): 303 mm², 15.174 N, eskisinin 3.2 katı. Menzile etkisi yok (1–2 cm).
Ayrıntı: `v1.1/dok/V1_1_OMUZ.md`.

**v1.1 → v1.2 — ilk baskıdan gelen iki düzeltme.** Kapsül namluda takılıyordu:
boşluk 0.30 → **0.80 mm** (yan başına 0.40; FDM'de Ø43 delik için 0.15 çok sıktı).
Bant ankrajındaki ön yüz oluğu kulağı zayıflatıyordu ve pim hiçbir yere
kenetlenmiyordu: yerine kulağın bir yan duvarından girip bandı delen ve
**karşı duvardaki deliğe oturan Ø4 enine pim** kondu. Ayrıntı: `v1.2/dok/V1_2.md`.

**v1.2 → v1.3 — ölçümler + kapsül içi.** Boncuk kumpasla **Ø8.80 mm / 4 g**,
bant **Ø13.59 mm** ölçüldü (eski varsayımlar Ø9.0 ve Ø13.0 idi). Kapsülde
üç sorun düzeltildi: ağ çıkış konisi **boncuk yuvalarının tabanını yiyordu**
(boncuklar hazneye düşüyordu) → her yuvanın etrafına boru füzelenip tabanı
kapatıldı, sadece Ø3 ip deliği kaldı; yuva ağzına **tutma dudağı** (Ø8.40 <
boncuk Ø8.80) eklendi; hazne→başlık geçişi **koni** yapıldı ve kapsül
**ağız yukarı** basılacak şekilde çevrildi — iç destek ve basamak kalmadı.
Bant ölçüm yöntemi: `v1.3/dok/BANT_OLCUMU.md`.

**v1.3 → v1.4 — ağ namluya taşındı.** 6 boncuk borusu 40° eğimli olduğu için
ağız düzleminde elips kesit veriyor ve R12 bölüm dairesinde çevrenin 72/75.4
mm'sini kaplıyordu: merkezde ağa **55 mm² (Ø8.3)** kalıyordu, 39 m ip oradan
geçmez. Ayar hatası değil, mimari çıkmaz — omuz ≥250 mm² için R_pitch ≤ 12.26
ve orada bile merkez 62 mm². **Durdurma omzu ile merkezi ağ çıkışı bir arada
olamaz.** Çözüm: ağ kapsülün değil, namlunun içinde, kapsülün önünde duruyor;
kapsül piston. Ağ hacmi 22.1 → **134.6 cm³**, doluluk %75 → **%8**. Başlık
masifleşti (kapsül 43.8 → 51.4 g, mesafe −0.02 m). Ayrıntı: `v1.4/dok/V1_4_AG_YERI.md`.

**v1.4 → v1.5 — iki kapsül.** Ağı içeride taşıyan varyant (`02b_kapsul_hazneli`)
da üretildi; boncuk düzeltmeleri ikisinde de aynı. Ağ çıkışını büyütmek için
boncuk bölüm dairesi cidarın izin verdiği en dışa itildi (R12.0 → 13.4):
merkezi bağlı boş alan 55 → **92 mm² (Ø10.8)**, 1.7×. Namlu başlığı
değişmiyor (boncuk dış kenarı 17.80 < koni 19.08), yani **aynı namlu ikisiyle
de çalışır**. 02b daha hafif (44.3 vs 51.4 g) ve biraz daha uzak; tek
belirsizlik 39 m ipin Ø10.8'den geçip geçmeyeceği — test edilecek.

**v1.5 → v2.0 — istenen mimari kuruldu, namlu büyüdü.** Ağ haznede, boncuklar
kapsülün ağzında; kapsül omza çarpınca önce boncuklar fırlıyor, ağı
arkalarından çekiyorlar. Ø43.4'te bu mümkün değildi: 6 yuva ağız çevresinde
74.4 mm istiyor ve 40° eğimden dolayı elips kesit veriyor, merkezde en fazla
Ø10.8 kalıyordu. **Namlu Ø43.4 → Ø55.0** ile ağ geçişi **Ø18.6 (271 mm²)**,
hazne doluluğu %51 → **%31**. Yuvalar da genişletildi (boşluk 0.4 → 0.8 mm,
dudak sıkması 0.4 → 0.2 mm — baskıda boncuklar zor giriyordu).
Bedeli: kapsül 44 → 71 g, baskı 214 → 281 g, menzil ~%10 kısa.
Ayrıntı: `v2.0/dok/V2_0.md`.

**v2.0 → v2.1 — boncuklar kapsülün kenarına alındı.** v2.0'da yuvalar R18.2'de
olduğu için 40° eğimden doğan elips kesit ağzın üstünü yiyordu; merkezde
271 mm² kalıyordu. Yuvalar **R22.0**'a, yani kapsül cidarına kadar itildi:
yuva dış kenarı 30.1 > cidar 27.1 olduğu için cidarı delip **en fazla 3.25 mm
genişliğinde radyal yarık** açıyor — boncuk Ø8.80 oradan **çıkamaz**, plastik
onu sarıyor, namlu deliği dışarıdan kapatıyor. Merkez **556 mm² (Ø26.6)**,
v2.0'ın 2.1 katı; hazne doluluğu %21. Koni R29.1'den başlamak zorunda olduğu
için omuz kalmadı; kapsülü **çapraz pim + namlu dışındaki durdurma takozu**
durduruyor (304 mm² / 15.200 N, TPU ped 10.9 J).

**v2.1 → v2.2 — namlu Ø64, omuz geri geldi.** v2.1'de kapsülü namlu
*dışındaki* takoz durduruyordu; takoz z 37–50 arasında, esnek bant ise
z 42.6–49.4'te — **takoz bandı engelliyordu**. Omza dönmek için koniye yer
gerekti: namlu **Ø55 → Ø64**. Boncuk çemberi R22 → R23, omuz 295 mm²
(14.744 N) geri geldi. Bant da **ölçüldü** (G·A0 = 54.7 N): kurma 391 N,
çıkış 17.4 m/s, marj 1.08×.

**v2.2 → v2.3 — takoz komple kaldırıldı.** Artık durdurmayı omuz yapıyor,
takozun işi kalmadı ve bandın yolunda duruyordu. `kontrol_bant_yolu.py`
eklendi: bant yolunu 121 nokta × 9 kesit köşesinde tarayıp namluyla
çakışma arıyor.

**v2.3 → v2.4 — boncuklar daha derine.** Yuva derinliği 9.0 mm, başlık
kalınlığı 11.0 mm: boncuk eğimli yuvada **7.5 mm** yol alıyor (önce 5.5),
yani 40° çıkış açısını tam kazanarak ayrılıyor.

**v2.4 → v2.5 — kapsül iki bloğa ayrıldı.** Çapraz pim arka bloktan
geçiyor ve yarık sonunda duruyor; kapsülün ağzı ise namlu omzuna çarpmak
zorunda. Tek parçada bu ikisi çelişiyordu. Kapsül yerel y=16'dan bölündü:
**alt blok** (pim + kanal + kurma deliği, 35.1 g) **üst bloğu**
(hazne + boncuk başlığı, 47.6 g) 594 mm² halka yüzünden itiyor; alt blok
yarık sonunda durunca üst blok serbest kalıp omza çarpıyor. Durdurma
enerjisi tek stop yerine ikiye bölündü (7.6 J + 12.3 J), omzun TPU ezilmesi
1.19 → **0.35 mm**. Ayrıntı: `dok/V2_5_IKI_BLOK.md`.

**v1 → v2 — uzun namlu + uzun bant.** λ sabit tutulunca kurma kuvveti strok'tan
bağımsız kalıyor (ikisi de 426 N), ama depolanan enerji bant hacmiyle 2.75×
büyüyor. Enerjinin menzile çevrilme verimi düşük (`mesafe ∝ strok^0.285`);
asıl kazanç, fazla enerjinin **daha düşük koni açısı** kullanmayı mümkün kılması
(v1'de 30° ağı açamıyordu). Ayrıntı: `v2/dok/V2.md`.

> v2 henüz **durdurma omuzunu almadı**. v1.1 testi iyi giderse v2'ye de
> uygulanmalı — v2'nin durdurma enerjisi 27.5 J, yani sorun daha büyük.

## Yeni versiyon dondurma

```
python3 versiyon_kaydet.py v3 "kısa açıklama"
```

CAD konfigini değiştirip şunları koşturduktan **sonra** çalıştır:

```
freecadcmd cad/lastik_montaj_v4.py     # katıları üret
freecadcmd cad/kontrol_omuz.py         # omuz + boncuk/koni açıklığı
freecadcmd cad/kontrol_ankraj.py       # bant ankrajı + koni çakışması
freecadcmd cad/baski_parcalari.py      # baski/ STL+STEP
freecadcmd cad/torna_parcasi.py        # çapraz pim (basılmaz)
python3 cad/baski_md_guncelle.py       # baskı ayarları tablosu
python3 malzeme_listesi.py             # BOM
```

## Konfig dosyaları

| Dosya | Ne |
|---|---|
| `cad_v4_konfig.json` | CAD giriş parametreleri (türetilmişler hariç) |
| `cad_v4_olcu.json` | CAD'in yazdığı **tam** ölçü dökümü (türetilmişler dahil) |
| `cad_v4_hacim.json` | her parçanın hacmi ve sınır kutusu |
| `out_v4_konfig.json` | simülasyon konfigi (ağ, boncuk, bant sayısı) |

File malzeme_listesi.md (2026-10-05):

# Ag Firlatici Namlu — Malzeme Listesi (v2, lastik bant)

Namlu 149.8 mm · strok 91 mm · kapsul 41 mm · bant 2x O16/4 lateks x4 · ag O2.2 m altigen

## A. 3D BASKI

| No | Parca | Adet | Malzeme / Ozellik | Olcu | Kutle [g] | Not |
|---|---|---|---|---|---|---|
| A1 | Namlu govdesi (bilezik + bant kulaklari + 2 tetik gobegi + 2 servo yatagi dahil) | 1 | PETG (tercih ASA - UV'ye dayanikli) | O55.4 dis / O43.4 ic x 149.8 mm, 2 duz yarik 6.4 mm | 238.3 | Dik bas (eksen Z), 4 cevre + %50 gyroid. Yariklar ve delikler destek istemez. |
| A2 | Kapsul (arka blok + tutma kanali + ag haznesi + 6 bilye yuvasi) | 1 | PETG | O43.1 x 41 mm, hazne O37.1 x 16 mm, yuva acisi 40 derece | 104.5 | Agiz yukari bas. Arka blok 16 mm yuk tasir: 5 cevre + %60 dolgu. |
| A3 | Tetik kartus kapagi | 2 | PETG | O18 x 3 mm, ortada O2 ip deligi, 2x O2.2 vida deligi | 1.9 | %100 dolgu. |
| A4 | Servo ip makarasi | 2 | PETG | O8 mm (r=4 mm) tambur, servo dislisine oturur, O1.5 ip deligi | 0.8 | Servonun kendi kol vidasiyla sabitlenir. |
| A5 | Yarik sonu durdurma tamponu | 2 | TPU 95A | 6.2 x 3 x 7 mm | 0.5 | Yarik on ucuna CA ile yapistir. Kapsulun carpma yukunu yumusatir (~450 N). |
| A6 | Arka toz kapagi (opsiyonel) | 1 | PETG | O43 tapa, ortada O10 havalandirma | 2.0 | Arka agiz yukleme agzidir; ucusta toz/kir girmesin diye. |

## B. METAL / ISLEME PARCALAR

| No | Parca | Adet | Malzeme / Ozellik | Olcu | Kutle [g] | Not |
|---|---|---|---|---|---|---|
| B1 | Capraz pim | 1 | Aluminyum 7075-T6 cubuk (alternatif: gumus celigi) | O8 x 124 mm; her ucta IKI oluk: r=46 ve r=57 mm, 2.4 mm genislik x 1 mm derinlik | 15.8 | 4 bant icin 4 oluk. Egilme SF 4.1 @ 1080 N. O6 YETERSIZ (SF 1.7). |
| B2 | Tetik pimi | 2 | Gumus celigi / paslanmaz cubuk | O5 x 20.7 mm, ust uctan 1 mm'de O1.5 enine ip deligi, uc hafif pahli | 6.6 | Uc kapsul kanalina girer; yuzey puruzsuz olmali. |
| B3 | Mil bilezigi (pim yakasi / yay tablasi) | 2 | Celik, set vidali (DIN 705) | O5 ic / O10 dis / 5 mm genislik, M3 set vida | 4.4 | Pim ucundan 12.2 mm'ye sabitlenir (dinlenmede uc kanal dibine 0.3 mm pay). |
| B4 | Geri getirme yayi (basma) | 2 | Yay celigi | ic O>=5.3, dis O<=10.2, tel ~0.5-0.6 mm, serbest boy ~13 mm, blok boy <=4 mm | 0.6 | Dinlenmede 10 mm (on yuk), cekilince 4 mm. Hazir yay setlerinden secilebilir. |
| B5 | Bant ankraj pimi | 2 | Paslanmaz celik pim | O4 x 16 mm | 3.2 | Agiz kulagindaki enine delige gecer, bant halkasini tutar. Uclara CA damlasi veya kucuk segman. |
| B6 | Ip yonlendirme pimi | 2 | Paslanmaz celik pim | O3 x 10 mm | 1.2 | Kapaktan radyal cikan ipi servo tamburuna cevirir. Puruzsuz olmali (veya O6 mini makara). |

## C. STANDART BAGLANTI ELEMANLARI

| No | Parca | Adet | Malzeme / Ozellik | Olcu | Kutle [g] | Not |
|---|---|---|---|---|---|---|
| B7 | PTFE burc (tetik pimi) | 2 | PTFE/teflon burc | ic O5.0 / dis O7 x 10 mm | 0.6 | Namlu delige gecer. Surtunmeyi mu=0.18'den 0.08'e dusurur - servo secimi buna bagli. |
| C1 | M2 isil gomme insert (heat-set) | 8 | Pirinc | M2 x 3 mm | 1.2 | 4 adet kapak vidasi + 4 adet servo vidasi icin (PETG'ye havyayla). |
| C2 | M2 x 6 civata (kapak) | 4 | Paslanmaz, silindir basli | M2 x 6 | 0.8 |  |
| C3 | M2 x 8 civata (servo) | 4 | Paslanmaz | M2 x 8 | 1.0 | Servonun kendi vidalari kisa kalirsa. |
| C4 | M3 set vida (mil bileziklerinin kendi vidasi) | 2 | Celik | M3 x 3 | 0.0 | Bilezikle gelir; diş sabitleyiciyle (Loctite 243). |

## D. TAHRIK — LATEKS BANT

| No | Parca | Adet | Malzeme / Ozellik | Olcu | Kutle [g] | Not |
|---|---|---|---|---|---|---|
| D1 | Lateks tup (zipkin lastigi) | 2 | SAF DOGAL KAUCUK LATEKS (silikon/EPDM OLMAZ) | O14 dis / O4 ic (ELDEKI ZIPKIN LASTIGI); kesim boyu ~130 mm (calisma 30 mm + on 45 + arka 55 mm delme/katlama payi) | 32.8 | KENAR BASINA 1 ADET. Kurulu uzama x4. SERTLIK OLCULMEDI — tek kol 50->135 mm cekip Gmod[MPa]=F[N]/308. 0.45 MPa'da 213 N/bant (22 kg), toplam kurma 426 N. |
| D2 | Enine tutma pimi (BANTI DELER) | 2 | Celik mil / cubuk | O4.0 x 26 mm (ucu hafif sivri) | 5.2 | Bant O14 delikten gecer; pim kulagin BIR yan duvarindan girer, bandi deler, KARSI duvardaki delige oturur. Delik O4.2, on yuzden 6 mm geride. O3 de sigar ama sert bantta egilme emniyeti 1.0'a dusuyor — O4 kullan. |
| D3 | Arka kilit pimi (BANTI DELER) | 2 | Celik mil | O4.0 x 25 mm | 5.0 | Bant capraz pimin 14 mm oluguna sarilir, tail 30 mm geri katlanir; bu pim ana kolu ve tail'i BIRLIKTE deler. Capraz pimin ~15 mm arkasina. |

## E. TETIK TAHRIK — ELEKTRIK

| No | Parca | Adet | Malzeme / Ozellik | Olcu | Kutle [g] | Not |
|---|---|---|---|---|---|---|
| E1 | Servo | 2 | MG996R sinifi (>=11 kg.cm @6V, metal disli) | 40 x 20 x 37 mm | 110.0 | Pim basina 213 N yuk -> PTFE burcla ~34 N cekme. Mikro servo YETMEZ. Iki servo AYNI sinyal (Y-kablo). Makara r=6 mm. |
| E2 | Servo Y-kablosu (1 giris -> 2 servo) | 1 | JR/Futaba 3 pin | ~15 cm | 4.0 |  |
| E3 | Servo uzatma kablosu | 1 | JR/Futaba 3 pin | gerekli boy (tarete gore) | 5.0 | Ucus kontrolcusundeki bir PWM cikisina. |
| E4 | Tetik ipi | 2 | PE/Dyneema orgu, PE #6 (~0.40 mm, ~30 kg) | her biri ~120 mm | 0.0 | Pim deliginden -> kapak deliginden -> yonlendirme piminden -> servo tamburuna. |
| E5 | Kablo bagi / spiral | 4 | Naylon | 2.5 mm genislik | 0.4 | Kablolari namluya sabitlemek icin. |

## F. AG VE BILYELER

| No | Parca | Adet | Malzeme / Ozellik | Olcu | Kutle [g] | Not |
|---|---|---|---|---|---|---|
| F1 | Ag ipi — goz + cevre halati + radyal baglar (HEPSI AYNI IP) | 1 | Hyper Dyneema orgu, O0.60 mm, 45.40 kg (ELDEKI IP) | altigen O2.2 m, kare goz 220 mm: 35.2 m kafes+halat + radyal baglar ve baglama paylari -> ~47 m kes | 12.9 | ELDE 90 m VAR — yeterli, 1 kez daha deneme payi birakir. Cevre halati icin ayri/kalin ip ALMA: ayni ip kullaniliyor. |
| F4 | Boncuk (bilye) | 6 | DELIKLI KURSUN boncuk — Captain 1216, O9 mm, 4 g/ad (ELDE VAR) | O9 mm, ortasi ~O2 mm delikli; yuva basina 1 ad (6 yuva) | 24.0 | ELDE VAR, satin alinacak degil. Delik sart: ip boncuklarin icinden gecer. |
| F5 | Kirilgan on kapak (her atis icin 1) | 1 | Ince kagit / pelur | O43 disk | 0.1 | Kapsul agzina yapistirici cubukla noktasal yapistirilir; bilyeleri ve ag paketini tutar, atista yirtilir. |

## G. SARF / YARDIMCI

| No | Parca | Adet | Malzeme / Ozellik | Olcu | Kutle [g] | Not |
|---|---|---|---|---|---|---|
| G1 | Yag (pim yuzeyleri icin) | 1 | Ince makine yagi (veya PTFE kuru yaglayici sprey) | birkac damla | 0.0 | PTFE sprey surtunmeyi yagin ~yarisina indirir -> servoya ek pay. |
| G2 | Dis sabitleyici | 1 | Loctite 243 (orta) |  | 0.0 | Mil bileziklerinin set vidalari. |
| G3 | Siyanoakrilat yapistirici (CA) | 1 |  |  | 0.0 | TPU tampon, ankraj pimi uclari. |
| G4 | Yapistirici cubuk | 1 |  |  | 0.0 | Kirilgan kagit kapak icin (zayif tutunmali). |
| G5 | Talk pudrasi (opsiyonel) | 1 |  |  | 0.0 | Paketlenen agda iplerin birbirine yapismasini azaltir. |

## H. TEST / KURULUM EKIPMANI

| No | Parca | Adet | Malzeme / Ozellik | Olcu | Kutle [g] | Not |
|---|---|---|---|---|---|---|
| H1 | Dijital bagaj kantari | 1 | 0-50 kg |  | 0.0 | Bant cekme testi + tetik ipi cekme kuvveti olcumu. |
| H2 | Kurma eldiveni | 1 | Kalin is eldiveni |  | 0.0 | Her bant ~34 kg cekilir; tek tek takilir. |
| H3 | Yedek bant seti | 1 | D1-D3 |  | 0.0 | Lateks yaslanir; testlerde surekli yedek bulundur. |
| H4 | Yuksek hizli kamera (telefon 240 fps) | 1 |  |  | 0.0 | Yer atisinda acilma suresi/cap olcumu. |

**Toplam (A-F, test ekipmani haric): ~583 g**

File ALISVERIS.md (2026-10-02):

# ALIŞVERİŞ LİSTESİ — Ağ Fırlatıcı v5
### Yanında götüreceğin tek dosya. Siparişe göre gruplandı.

> Tüm linkler sayfa içeriğinden doğrulandı. Trendyol / Hepsiburada / n11 /
> Koçtaş bot korumasıyla okunamadığı için **o platformlardan link yok**.
> **Fiyatlar Ekim 2026 itibarıyla — değişebilir.**

---

# ⛔ ÖNCE BUNLARI OKU — 7 KRİTİK UYARI

**1. LASTİK — en kolay kazık yiyeceğin kalem**
Ambalajda/sayfada **"doğal lateks / natural latex"** geçmeli.
Silikon, EPDM, SBR **OLMAZ** — enerji yoğunluğu üçte biri, menzil yarıya iner.
→ **Aldıktan sonra MUTLAKA test et:** bagaj kantarıyla **135 mm**'ye ger,
**~30 kg** çekmeli. %25 altındaysa sentetiktir, **kullanma**.
→ *İç çapın sayfada yazmaması SORUN DEĞİL* — iç çap ±1 mm kuvveti sadece
**%4** değiştiriyor. Kritik olan dış çap (Ø15-16) ve doğal lateks.

**2. İP — ÖRGÜ olacak**
"Örgü / braid / PE / Dyneema" yazmalı. **MONOFİLAMENT (misina) ALMA.**
Misina pervane kenarına sarılınca %19 bükülme gerinimi görür (kopma gerinimi
%3.3) → **ilk temasta kırılır**. Örgüde bükülmeyi tek filament belirler (%2).

**3. ÇAPRAZ PİM — 7075-T6 Türkiye'de YOK**
Ø8 7075 satılmıyor (7075 Ø13'ten başlıyor). **CİVA ÇELİĞİ Ø8 al** (SF 2.2).
❌ **6063 alüminyum SF 0.84 → KIRILIR.** ❌ **304 paslanmaz SF 1.04 → yetersiz.**
Satıcı "alüminyum var" derse alma; "civa çeliği" veya "gümüş çeliği" iste.

**4. KURŞUN — zeytin form işe yaramaz**
Tasarım **Ø12.7 mm = tam 12.16 g** küre istiyor. Piyasadaki zeytin kurşun
**oval** → Ø12.9 yuvaya oturmaz. Misket seri 8 g'da bitiyor.
→ **.50 kalibre yuvarlak kurşun al, 2 mm matkapla kendin del.** Kurşun çok
yumuşak, el matkabıyla 1 dakika.

**5. SERVO — MG996R ALMA, MİKRO SERVO AL**
**MG996R 110 g = sistemin %22'si.** Makara r=2.2 mm + kanal 4 mm ile gereken
tork **2.15 kg·cm**'ye düştü; **mikro metal dişli servo** (Savöx SH-0255MG /
MG92B sınıfı, **~14 g**, ≥3.5 kg·cm) **1.81× payla** yetiyor.
→ **−82 g** (sistem 492 → 410 g; namlu 150 mm ile **390 g**). ❌ MG996R ve DS3218'e GEREK YOK.
⚠️ **METAL DİŞLİ ŞART** — mikro servoların plastik dişlileri sıyırır.
⚠️ Bağlantı deliği aralığı **28 mm** olmalı (namludaki yatak buna göre).

**6. Y-KABLO — yalnızca SİNYAL**
İki servonun stall akımı 2.5 A/adet = **5 A**. 22AWG Y-kablo ve alıcı
regülatörü yanar. **+5V ve GND'yi her iki servoya doğrudan BEC'ten çek.**

**7. YAY SETİ — tel çapı hiçbir sayfada yazmıyor**
Set gelince **kumpasla ölç**. Aradığın: iç çap **≥5.3 mm**, dış ≤10.2 mm,
serbest boy ~13 mm. (Sette 7×12,5 mm yay var, hedefe uyuyor.)

---

# 📦 SİPARİŞ 1 — MetalAVM  ·  *hammadde, önce bunu ver*
https://metalavm.com · yerli, TR içi kargo

| ☐ | Parça | Spec (kritik olan) | Adet | Satıcı | Link | Fiyat | Not |
|---|---|---|---|---|---|---|---|
| ☐ | **B1 ham: Civa çeliği Ø8** | 1.2210, Ø8.00 — **7075 DEĞİL** (TR'de yok), 6063/304 yetersiz | 2 m | MetalAVM | [link](https://metalavm.com/civa-celigi-1-2210-800-mm) | ~360 TL + KDV | Çapraz pim buradan çıkacak. **Paslanır → yağla.** Tornaya bu gidecek |
| ☐ | **B2 ham: Civa çeliği Ø5** | 1.2210, Ø5.00, yüzey pürüzsüz | 2 m | MetalAVM | [link](https://metalavm.com/civa-celigi-1-2210-500-mm) | ~148 TL + KDV | 2 tetik pimi (20.7 mm) |
| ☐ | **B5 ham: Civa çeliği Ø4** | Ø4.00 | 2 m | MetalAVM | [link](https://metalavm.com/civa-celigi-1-2210-400-mm) | ~120 TL + KDV | 4 bant ankraj pimi (16 mm) |
| ☐ | **B6 ham: Civa çeliği Ø3** | Ø3.00 | 2 m | MetalAVM | [link](https://metalavm.com/civa-celigi-1-2210-300-mm) | ~75 TL + KDV | 2 ip yönlendirme pimi (10 mm) |
| ☐ | *(ops.)* **B3 ham: Ø10 çubuk** | mil bileziği yapılacak | 20 cm | MetalAVM | aynı site, Ø10 | ~50 TL | RS'teki hazır bilezik 305 TL/ad — tornada yaptır |

**ARA TOPLAM ≈ 700-750 TL + KDV**

> ⚠️ **Kısa boy satan online satıcı yok** — 2 m almak zorundasın. Ucuz ve
> ömür boyu yeter. Sepet tutarına göre %2-4 indirim var.

---

# 📦 SİPARİŞ 2 — mertsubonline  ·  *lastik*

| ☐ | Parça | Spec (kritik olan) | Adet | Satıcı | Link | Fiyat | Not |
|---|---|---|---|---|---|---|---|
| ☐ | **D1 Zıpkın lastiği** | Ø16 dış, metraj — sayfada **"%100 doğal lateks kauçuk"** yazıyor ✅ | 1 m | mertsubonline | [link](https://www.mertsubonline.com/urun/o-m-e-r-performer-2-o16mm-metraj-lastik) | 1.367,80 TL | O.M.E.R Performer 2. **1 m seç.** 4 adet × **50 mm** kesilecek |

**ARA TOPLAM ≈ 1.370 TL**

> **Alternatif (daha ucuz ama ÖDÜNLÜ):** Free-Sub 16mm × 100cm —
> [daliselbisesi](https://daliselbisesi.com/products/free-sub-metraj-zipkin-lastigi-16mm-x-100cm-zipkin-lastik) — 1.113,60 TL.
> ⚠️ **Çift komponentli**: çekirdek doğal lateks, dış kılıf **sentetik**.
> "Silikon olmaz" şartını geçer ama "saf doğal" şartını tam karşılamaz.
> Alırsan kantar testini **mutlaka** yap.

---

# 📦 SİPARİŞ 3 — avmarketi  ·  *iki ip, tek kargo*

| ☐ | Parça | Spec (kritik olan) | Adet | Satıcı | Link | Fiyat | Not |
|---|---|---|---|---|---|---|---|
| ☐ | **F1 Ağ gözü ipi** | **ÖRGÜ** Dyneema, **0,16 mm / 9,07 kg** ✅ sayfada doğrulandı | 100 m | avmarketi | [link](https://www.avmarketi.com/urun/dft-bojin-dyneema-ip-misina-100-m-0-16-mm-yesil) | 129,51 TL | 45 m lazım. **Misina ALMA** |
| ☐ | **F2 Çevre halatı** | **ÖRGÜ** Dyneema, **0,30 mm / 22,67 kg** ✅ | 100 m | avmarketi | [link](https://www.avmarketi.com/urun/dft-bojin-dyneema-ip-misina-100-m-0-30mm-yesil) | 415,32 TL | 7,8 m lazım. Hedef 18 kg, bu 22,67 → güvenli yönde |
| ☐ | **E4 Tetik ipi + D2 bant halkası** | aynı makaradan kesilebilir | — | — | — | — | F2'den artan yeterli |

**ARA TOPLAM ≈ 545 TL**

---

# 📦 SİPARİŞ 4 — Robot Sepeti  ·  *servo + civata*

| ☐ | Parça | Spec (kritik olan) | Adet | Satıcı | Link | Fiyat | Not |
|---|---|---|---|---|---|---|---|
| ☐ | **E1 Servo** | **MİKRO, METAL DİŞLİ, ≥3.5 kg·cm @6V** — Savöx SH-0255MG / MG92B sınıfı, ~14 g, delik aralığı 28 mm | **2** | RC hobi mağazası | *(TEDARIK_PLANI'nda MG996R linki vardı — ARTIK GEÇERSİZ, yeni arama gerekli)* | — | **MG996R ALMA** — 110 g, gereksiz ağır. Mikro servo 28 g, −82 g kazanç |
| ☐ | **C2 M2×6 civata** | DIN 912, A2 304 inox, silindir baş ✅ | 10'lu | Robot Sepeti | [link](https://www.robotsepeti.com/m2x6-imbus-civata-paslanmaz) | 43,36 TL | 4 lazım (kapak) |
| ☐ | **C3 M2×8 civata** | DIN 912, A2 304 inox ✅ | 10'lu | Robot Sepeti | [link](https://www.robotsepeti.com/m2x8-imbus-civata-10lu) | 37,34 TL | 4 lazım (servo) |

**ARA TOPLAM ≈ 595 TL**
> Civatalar 1-4 iş günü tedarikli — siparişi erken ver.

---

# 📦 SİPARİŞ 5 — hiber.com.tr  ·  *kablolar*

| ☐ | Parça | Spec (kritik olan) | Adet | Satıcı | Link | Fiyat | Not |
|---|---|---|---|---|---|---|---|
| ☐ | **E2 Y-kablo** | **1 JR erkek → 2 Futaba dişi** ✅ tam istenen | 1 | hiber | [link](https://www.hiber.com.tr/30-cm-y-tipi-servo-kablosu) | 71,71 TL | ⚡ **SADECE SİNYAL**, bkz. Uyarı 6 |
| ☐ | **E3 Uzatma kablosu** | 30 cm, Futaba, dişi-erkek ✅ | 1 | hiber | [link](https://www.hiber.com.tr/servo-uzatma-kablosu-30-cm-disi-erkek) | 85,33 TL | Taret mesafesine göre |

**ARA TOPLAM ≈ 157 TL**

---

# 📦 SİPARİŞ 6 — tek kalemlikler  *(ayrı kargo, birleştirilemiyor)*

| ☐ | Parça | Spec (kritik olan) | Adet | Satıcı | Link | Fiyat | Not |
|---|---|---|---|---|---|---|---|
| ☐ | **C1 M2×3 insert** | Ø3.2 dış / 3 mm / pirinç ✅ **spec %100** | 10 | robotizmo | [link](https://www.robotizmo.net/en/insert-cakma-somun-m2-yukseklik-3mm) | 4,71 ×10 = **47 TL** | 8 lazım. Havyayla gömülür (220 °C) |
| ☐ | **H1 Bagaj kantarı** | 50 kg / **10 g**, **VERİ KİLİTLEME** ✅ | 1 | kalitelial | [link](https://kalitelial.com/product/dijital-el-kantari-ve-hassas-valiz-terazisi-50-kg-kapasiteli-termometreli-askili-tarti) | 289 TL | **Veri kilitleme şart** — bant testinde tepe değeri tutacak |
| ☐ | **G1 PTFE kuru sprey** | "yağ içermez, kuru film" ✅ | 1 | kulucteknik | [link](https://kulucteknik.com/urun/ptfe-kuru-yaglama-sprey-400ml) | 209 TL | Hırdavatçı "teflon sprey" diye **ıslak/silikonlu** verebilir — dikkat |
| ☐ | **G2 Loctite 243** | orta mukavemet, 10 ml | 1 | yildizburo | [link](https://yildizburo.com) | 515 TL | 10 ml yüzlerce vidaya yeter. Yerelde "mavi vida gevşemezlik" muadili de olur |
| ☐ | **B4 Yay seti 200 parça** | içinde 7×12,5 mm var ✅ (**tel çapı sayfada yok**) | 1 | worldforce | [link](https://www.worldforce.com.tr/urun/yay-seti-200-parca) | 671,80 TL | Kargo bedava. **Gelince kumpasla ölç**, bkz. Uyarı 7 |
| ☐ | **B7 ham: PTFE çubuk** | Ø8 veya Ø10, **20 mm'den kesim yapıyor** ✅ | ~30 mm | martanonline | [link](https://martanonline.com/product/ptfe-teflon-cubuk-beyaz/) | 750 TL/kg → malzeme ~3 TL | ⚠️ **Minimum sipariş tutarını sor** — kargo malzemeden pahalı olacak. Tornaya bu gidecek |

**ARA TOPLAM ≈ 1.730 TL** *(PTFE minimum sipariş hariç)*

---

# 🏪 YERELDEN AL — online almak mantıksız

| ☐ | Parça | Hangi dükkân | Neye dikkat |
|---|---|---|---|
| ☐ | **F4 Kurşun bilye ×6** *(10 al)* | **Av malzemesi / atış sporu** | **.50 kalibre yuvarlak kurşun** iste (tam Ø12.7 = 12.16 g). **Zeytin form ALMA — oval, yuvaya oturmaz.** Eve gelince **2 mm matkapla del** |
| ☐ | **G5 Talk pudrası** | **Eczane** | Bebek pudrası 100-200 g yeter. Online'da 1 kg endüstriyel çuval çıkıyor |
| ☐ | **G3 CA yapıştırıcı** | Hırdavatçı / kırtasiye | Japon yapıştırıcı 3-20 gr. **Jel değil, sıvı** al (TPU'ya nüfuz etsin) |
| ☐ | **G4 Yapıştırıcı çubuk** | Kırtasiye | Pritt vb. **Zayıf tutmalı** — kâğıt kapak atışta yırtılacak |
| ☐ | **H2 Koruyucu gözlük** | Hırdavatçı / İSG dükkânı | **EN166 "F" sınıfı yeterli** (45 m/s). "B" gerekmez. **Yüze oturmasını dene** |
| ☐ | **H2 İş eldiveni** | Hırdavatçı | **Avuç içi deri** takviyeli. Kesilme direnci değil **tutuş+aşınma** önemli. **Bedeni elle dene** |
| ☐ | **F5 Pelur kâğıt** | Kırtasiye | Ø43 disk kesilecek |
| ☐ | **E5 Kablo bağı** | Hırdavatçı | 2.5 mm, 10 adet |
| ☐ | **D3 Sargı ipliği** | Tuhafiye | Kalın naylon dikiş ipliği, 2 m |

---

# 🔧 TORNACIYA GÖTÜR — tek ziyaret, 5 parça

**Yanında götür:** `TORNA_IS_EMRI.png` (B1 ve B2 ölçülü teknik resim)
+ MetalAVM'den gelen çubuklar + PTFE çubuk.
**Malzemeyi sen götür** — onlardan alırsan pahalanır.

| ☐ | Parça | Adet | Hammadde | Yapılacak iş |
|---|---|---|---|---|
| ☐ | **B1 Çapraz pim** | 1 | Civa çeliği **Ø8** | 92 mm kes + merkezden ±33 ve ±44 mm'de **4 oluk** (2.4 geniş × 1.0 derin, dip Ø6) |
| ☐ | **B2 Tetik pimi** | 2 | Civa çeliği **Ø5** | 20.7 mm kes + bir uca hafif pah + diğer uçtan 1 mm'de **Ø1.5 enine delik** |
| ☐ | **B7 PTFE burç** | 2 | PTFE çubuk Ø8-10 | Dış **Ø7**, iç **Ø5.0**, boy **10 mm** |
| ☐ | **B3 Mil bileziği** | 2 | Civa çeliği Ø10 | 6 mm kes, **Ø5 del**, yandan **M3 kılavuz** (set vidası için) |
| ☐ | **B5/B6 Pimler** | 4+2 | Civa çeliği Ø4 / Ø3 | Ø4'ten **4 × 16 mm**, Ø3'ten **2 × 10 mm** kes, çapak al |

> **Tolerans ±0.1 mm.** Oluk derinliğini fazla açtırma — 1 mm'den derin
> olursa pim zayıflar. **Ø8'i Ø6'ya düşürme teklifini KABUL ETME**
> (emniyet katsayısı 2.2'den yarıya iner).
> İş toplam **~yarım saat**. Fiyat için resmi göster, teklif al —
> güncel atölye fiyatlarını doğrulayamadığım için rakam yazmıyorum.

---

# 📅 SİPARİŞ SIRASI — en uzun süren iş önce

```
1. MetalAVM + PTFE çubuk ver        ← EN UZUN ZİNCİR (metal → torna)
2. Aynı gün paralel: lastik, ipler, servo, kablolar, tek kalemlikler
3. 3D baskıları başlat               ← namlu ~14 saat (baski/ klasörü)
4. Metal gelince TORNAYA git
5. Yerel alışveriş (kurşun, talk, CA, gözlük, eldiven)
6. Hepsi tamam → montaj: URETIM_MONTAJ_REHBERI.md
```

# 💰 TAHMİNİ TOPLAM

| Grup | Tutar |
|---|---|
| Sipariş 1 — MetalAVM (hammadde) | ~700-750 TL + KDV |
| Sipariş 2 — lastik | ~1.370 TL |
| Sipariş 3 — ipler | ~545 TL |
| Sipariş 4 — servo + civata | ~595 TL |
| Sipariş 5 — kablolar | ~157 TL |
| Sipariş 6 — tek kalemlikler | ~1.730 TL |
| Yerel (kurşun, sarf, güvenlik) | ~400 TL |
| **ARA TOPLAM** | **≈ 5.500 TL** |
| 3D baskı filament (~190 g PETG + TPU) | ~150-250 TL |
| **Torna işçiliği** | **teklif alınacak** |

*(Ekim 2026, değişebilir)*

---

# ❌ BULUNAMADI — ve çözümleri

| Kalem | Neden bulunamadı | **Çözüm** |
|---|---|---|
| **Ø8 7075-T6 alüminyum** | TR'de çekme 7075 Ø13'ten başlıyor | **Civa çeliği Ø8** (SF 2.2 vs 2.4) — +23 g |
| **Hazır PTFE burç 5/7×10** | TR'de online stoktan yok, hepsi teklif usulü | **PTFE çubuktan tornada** yaptır |
| **Ø5 mil bileziği (DIN 705)** | Tek kaynak RS, 305 TL/ad + stok teyidi | **Ø10 çubuktan tornada** yaptır |
| **12 g delikli kurşun bilye** | Misket 8 g'da bitiyor, zeytin oval | **.50 kalibre yuvarlak kurşun + kendin del** |
| **Tam metal dişli MG996R** | TR'dekilerin hepsi "half metal" | **Zaten gerekmiyor** — MİKRO metal dişli servoya geçildi (r=2.2 mm makara, 1.81× pay, −82 g) |
| **Ø4/Ø3 hazır paslanmaz pim** | Civata sitelerinin hiçbirinde fiyat doğrulanamadı | **Çubuktan kes** (Sipariş 1'e dahil) |

---

### Bu dosyanın kaynakları
Teknik özellikler: `malzeme_listesi.md` · Doğrulanmış linkler: `TEDARIK_PLANI.md`
3D baskı: `baski/BASKI_AYARLARI.md` · Montaj: `URETIM_MONTAJ_REHBERI.md`

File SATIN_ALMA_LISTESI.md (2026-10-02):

# SATIN ALMA LİSTESİ — Ağ Fırlatıcı v5

3D baskı parçaları **bu listede yok** (onlar `baski/` klasöründe, ~190 g PETG
+ 0.2 g TPU). Burada **satın alman gereken her şey** var.

## Nasıl okunacak

| İşaret | Anlamı |
|---|---|
| 🔴 **KRİTİK** | Muadili **olmaz**. Yanlışı sistemi çalışmaz kılar veya tehlikeli yapar. |
| 🟡 **ÖNEMLİ** | Muadili olur ama ölçü/sınıf tutmalı. |
| ⚪ **SERBEST** | Eşdeğeri neyse olur. |

---

## 1. TAHRİK — lastik (en kritik kalem)

| # | Ne | Adet | Spec |
|---|---|---|---|
| D1 | 🔴 **Zıpkın lastiği (speargun rubber)** | 4 × 50 mm → **1 metre al** | Ø15.2 (veya Ø16) dış / Ø4 iç |

**🔴 MUTLAKA SAF DOĞAL KAUÇUK (natural latex).**
Silikon, EPDM, SBR, "sentetik kauçuk" **OLMAZ** — enerji yoğunlukları
doğal lateksin üçte biri kadar, menzil yarıya düşer.

**Nereden:** dalış / zıpkın malzemesi satan mağazalar, su altı avcılığı
dükkânları. Online: "zıpkın lastiği 16mm", "speargun rubber latex",
"tüplü dalış harpun lastiği".

**Satın alırken sor:** *"Bu saf doğal kauçuk mu, sentetik mi?"*
Ucuz olanların çoğu sentetiktir. Marka olarak dalış sektöründe bilinen
üreticiler (Omer, Salvimar, Rob Allen, Picasso sınıfı) genelde saf lateks
kullanır; isimsiz ucuz lastiklerde risk var.

**Doğrulama (şart):** aldıktan sonra **bagaj kantarıyla test et** —
135 mm'ye gerdiğinde **~30 kg** çekmeli. %25 altındaysa sentetiktir, kullanma.

| # | Ne | Miktar |
|---|---|---|
| D2 | 🟡 Dyneema/UHMWPE örgü halat Ø1.5 mm (bant uç halkası) | 1 m |
| D3 | ⚪ Naylon dikiş ipliği, kalın (uç sargısı) | 5 m |

**Nereden:** yelken/denizcilik malzemesi, olta malzemesi, veya kalın
Dyneema olta ipi. D3 için normal kalın dikiş ipliği yeterli.

---

## 2. AĞ

| # | Ne | Miktar | Spec |
|---|---|---|---|
| F1 | 🔴 **Dyneema ÖRGÜ olta ipi** | **100 m makara** (45 m lazım) | PE #1, ~0.165 mm, 8-9 kg |
| F2 | 🟡 Dyneema ÖRGÜ olta ipi (çevre halatı) | 10 m | PE #3, ~0.285 mm, 18 kg |
| F4 | 🔴 **DELİKLİ kurşun balık ağırlığı** | **10 adet** (6 lazım) | ~12 g, Ø12.7 mm |
| F5 | ⚪ Pelur kâğıt / ince kâğıt | 1 paket | kapsül ağzı kapağı |

**🔴 F1 — MONOFİLAMENT (misina) ALMA.** "Örgü ip", "braid", "PE line"
olacak. Misina pervane kenarına sarılınca %19 bükülme gerinimi görür ve
**ilk temasta kırılır**; örgüde bükülmeyi tek filament (~15-20 µm)
belirler, %2 gerinim, dayanır.

**🔴 F4 — deliği olmayan çelik bilye ALMA.** İp bağlanamaz.
Kurşun seçildi çünkü çelikten ağır → atış penceresi %20-30 daha geniş.

**Nereden:** balıkçı malzemesi dükkânları. Online: "PE örgü olta ipi 0.16",
"braided fishing line PE1", "delikli kurşun balık ağırlığı 12 gr",
"zeytin kurşun delikli".

**Satın alırken:** PE numarası yerine **çap ve kg** bak — markalar arası
PE numarası tutarsız. Hedef: **0.165 mm / 8-9 kg** ve **0.285 mm / 18 kg**.

---

## 3. METAL — işleme gerektirenler

| # | Ne | Adet | Spec | İşlem |
|---|---|---|---|---|
| B1 | 🔴 Alüminyum **7075-T6** çubuk | Ø8 × 100 mm | çapraz pim | **4 oluk açılacak** |
| B2 | 🟡 Gümüş çeliği / paslanmaz çubuk | Ø5 × 50 mm | 2 tetik pimi | kesim + Ø1.5 enine delik |

**B1 oluk detayı:** her iki uçta **ikişer oluk** — merkezden r=33 mm ve
r=44 mm'de, 2.4 mm genişlik × 1 mm derinlik. Toplam 4 oluk (4 bant için).

**🔴 Ø8 şart, Ø6 YETERSİZ.** Ø6'da eğilme emniyet katsayısı 1.7'ye düşüyor
(1080 N altında), Ø8'de 4.1.

**Nereden:** metal/hırdavat (alüminyum çubuk), **oluklar için torna
atölyesi** — küçük bir iş, yarım saat. Ölçüleri yazılı götür.
Alternatif: 7075 bulamazsan **gümüş çeliği (silver steel)** Ø8 kullan,
daha ağır ama daha güçlü.

**B2:** tornacı kesip delsin, ya da kendin kesip **Ø1.5 mm matkapla**
uçtan 1 mm'de enine delik aç. Yüzey pürüzsüz olmalı (pim burçta kayacak).

---

## 4. METAL — hazır alınanlar

| # | Ne | Adet | Spec |
|---|---|---|---|
| B3 | 🟡 Mil bileziği, set vidalı (DIN 705) | 2 | iç Ø5 / dış Ø10 / 5 mm, M3 set vida |
| B4 | 🟡 Basma yayı | 2 | iç ≥5.3, dış ≤10.2, tel 0.5-0.6, serbest ~13 mm |
| B5 | ⚪ Paslanmaz pim/mil | 4 | Ø4 × 16 mm (bant ankrajı) |
| B6 | ⚪ Paslanmaz pim/mil | 2 | Ø3 × 10 mm (ip yönlendirme) |
| B7 | 🟡 **PTFE (teflon) burç** | 2 | iç Ø5.0 / dış Ø7 × 10 mm |

**B7 neden önemli:** sürtünmeyi µ=0.18'den 0.08'e düşürüyor —
**servo seçimi buna bağlı**. Bulamazsan Ø8 teflon çubuk alıp
Ø5 delip kesebilirsin.

**B4:** tek tek aramak yerine **"basma yay seti"** (karışık ölçü, 200+
parça) al, içinden uyanı seç. Ucuz ve pratik.

**Nereden:** rulman/mil bileziği satan hırdavatçılar, online
"shaft collar 5mm", "mil bileziği 5mm set vidalı", "basma yay seti",
"teflon burç", "ptfe bushing 5x7".

---

## 5. BAĞLANTI ELEMANLARI

| # | Ne | Adet |
|---|---|---|
| C1 | 🟡 **M2×3 ısıl gömme insert** (heat-set, pirinç) | 8 (10 al) |
| C2 | ⚪ M2×6 civata, silindir başlı paslanmaz | 4 |
| C3 | ⚪ M2×8 civata paslanmaz | 4 |

**Nereden:** 3D baskı malzemesi satanlar (insert), hırdavatçı (civata).
Online: "heat set insert M2", "ısıl gömme somun M2", "M2 civata seti".

> Insert oturtmak için **havya** lazım (220 °C). Yoksa alternatif:
> deliği Ø1.6'ya daraltıp doğrudan M2 vida diş açarak kullan — daha zayıf
> ama bu parçalarda (kapak, servo) yeterli.

---

## 6. ELEKTRİK

| # | Ne | Adet | Spec |
|---|---|---|---|
| E1 | 🔴 **Servo, MG996R sınıfı** | 2 | **≥11 kg·cm @6V, METAL dişli** |
| E2 | ⚪ Servo Y-kablosu (1→2) | 1 | JR/Futaba 3 pin |
| E3 | ⚪ Servo uzatma kablosu | 1 | boy ihtiyaca göre |
| E4 | ⚪ Dyneema örgü ip (tetik ipi) | 50 cm | PE #6, ~0.40 mm, 30 kg |
| E5 | ⚪ Kablo bağı | 10 | 2.5 mm |

**🔴 METAL DİŞLİ ŞART** — plastik dişli sıyırır. Ama **MG996R gereksiz ağır** (55 g):
makara r=2.2 mm ile gereken tork 2.15 kg·cm, mikro servo (~14 g) 1.81× payla yetiyor.

**İki servo AYNI sinyali alacak** (Y-kablo) — asimetrik çekiş kapsülü
yana kaydırır.

**Nereden:** RC hobi mağazaları. Online: "MG996R servo", "metal dişli
servo 11kg", "servo y kablosu".

---

## 7. SARF MALZEME

| # | Ne | Not |
|---|---|---|
| G1 | 🟡 **PTFE kuru yağlayıcı sprey** | Pim yüzeyleri. Yağdan iyi — sürtünmeyi yarıya indirir |
| G2 | ⚪ Loctite 243 (orta mukavemet) | Mil bileziği set vidaları |
| G3 | ⚪ Siyanoakrilat (CA / japon yapıştırıcı) | TPU tampon, pim uçları |
| G4 | ⚪ Yapıştırıcı çubuk (stick) | Pelur kâğıt kapak — **zayıf tutmalı** |
| G5 | ⚪ Talk pudrası | Ağ paketlerken ipler yapışmasın |

**Nereden:** hırdavatçı, nalbur, eczane (talk).

---

## 8. TEST / GÜVENLİK EKİPMANI — atlanmaz

| # | Ne | Neden |
|---|---|---|
| H1 | 🔴 **Dijital bagaj kantarı 0-50 kg** | Lastiğin gerçek olup olmadığını **bununla** anlayacaksın |
| H2 | 🔴 **Koruyucu gözlük** | Kurarken 120 kg depolanıyor |
| H3 | 🔴 **Kalın iş eldiveni** | Her bant ~31 kg elle çekilecek |
| H4 | 🟡 Yedek lastik seti | Lateks yaşlanır, testlerde sürekli lazım |
| H5 | ⚪ Telefon (240 fps çekim) | Ağ açılma testi (§T3) |

---

## 9. ÖZET — alışveriş rotası

| Nereye | Ne alacaksın |
|---|---|
| **Balıkçı malzemesi** | Örgü olta ipi ×2 kalınlık, delikli kurşun ağırlık |
| **Dalış / zıpkın mağazası** | 🔴 Saf lateks zıpkın lastiği (1 m) |
| **RC hobi mağazası** | MG996R servo ×2, Y-kablo, uzatma |
| **Hırdavat / nalbur** | Alüminyum çubuk, paslanmaz pim, civata, mil bileziği, yay seti, PTFE sprey, Loctite, CA |
| **Torna atölyesi** | B1 çapraz pime 4 oluk, B2 pim kesimi+delik |
| **Online (Trendyol/Hepsiburada/n11 vb.)** | Teflon burç, heat-set insert, bagaj kantarı, basma yay seti |
| **Eczane** | Talk pudrası |

---

## 10. ALIRKEN EN ÇOK HATA YAPILACAK 5 KALEM

1. **Lastik sentetik çıkar** → menzil yarıya düşer. *Bagaj kantarıyla test et.*
2. **Misina alınır** (örgü yerine) → pervane ilk temasta koparır.
3. **Deliksiz çelik bilye alınır** → ip bağlanamaz, baştan başlarsın.
4. **Mikro/plastik dişli servo alınır** → pim çekilmez, dişli sıyırır.
5. **Çapraz pim Ø6 alınır** → emniyet katsayısı 1.7, eğilir.

---

## 11. TOPLAM

```
3D baskı     : PETG ~190 g + TPU ~0.2 g        (baski/ klasörü)
satın alınan : ~45 kalem, sistem kütlesi ~469 g
işleme işi   : 1 torna ziyareti (B1 olukları + B2 pim)
```

Detaylı teknik özellikler ve her parçanın nereye gittiği:
**`malzeme_listesi.md`**
Montaj sırası ve nasıl yapılacağı: **`URETIM_MONTAJ_REHBERI.md`**

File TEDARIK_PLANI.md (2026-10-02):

# TEDARİK PLANI — doğrulanmış linkler ve sipariş sırası

> Tüm linkler tek tek **açılıp sayfa içeriğinden** doğrulandı.
> Trendyol / Hepsiburada / n11 / Koçtaş bot korumasıyla okunamadı — o
> platformlardan link **verilmedi** (ürün olabilir, ama doğrulayamadım).
> **Fiyatlar Ekim 2026 itibarıyla, değişebilir.**

---

## ⚠️ ARAŞTIRMANIN DEĞİŞTİRDİĞİ 2 TASARIM KARARI

### 1. Çapraz pim: 7075-T6 → **civa çeliği (gümüş çeliği)**
Türkiye'de **Ø8 mm 7075-T6 satılmıyor** — çekme 7075 Ø13'ten başlıyor
(aluminyumburada.com stok listesinden doğrulandı).

Tasarım gerilmesini hesapladım: kapsül kenarında M = 10170 N·mm → **202 MPa**.

| malzeme | akma | SF | karar |
|---|---|---|---|
| 7075-T6 *(hedef, TR'de yok)* | 480 MPa | 2.4× | — |
| **civa çeliği 1.2210** | 450 MPa | **2.2×** | ✅ **KULLAN** |
| 6061-T6 | 276 MPa | 1.4× | sınırda |
| 6063 *(piyasada bulunan Al)* | 170 MPa | **0.84×** | ❌ KIRILIR |
| 304 paslanmaz | 210 MPa | **1.04×** | ❌ yetersiz |

**Bedeli:** pim 13 g yerine 36 g (+23 g). Paslanır,
yağlanmalı (zaten pimleri yağlıyoruz).

### 2. Servo: MG996R → **MİKRO servo** (makara r=2.2 mm)
MG996R **110 g = sistemin %22'si** idi. İş korunumlu: `tork × açı =
F_pim × strok`. r=4 mm makara servonun dönüş aralığının yalnızca 86°'sini
kullanıyordu; **r=2.2 mm + kanal 4 mm** ile 130° kullanılıyor ve gereken
tork **3.9 → 2.15 kg·cm**'ye düşüyor.
→ **mikro metal dişli servo** (Savöx SH-0255MG / MG92B sınıfı, ~14 g,
≥3.5 kg·cm) **1.81× payla** yetiyor. **−82 g.** Namlu 150 mm ile birlikte sistem **390 g**.
Namlunun servo yatağı zaten M2/mikro için tasarlanmıştı; delik aralığı
18 → 28 mm'ye düzeltildi (oval, marka farkını tolere eder).

---

## 🔧 TEK TORNA ZİYARETİ — 5 sorunlu kalemi birden çözüyor

Zaten çapraz pim olukları için tornacıya gideceksin. **Aynı ziyarette
şunları da yaptır** — hepsi ya TR'de bulunamıyor ya çok pahalı:

| Parça | Normalde sorun | Tornada çözüm | Hammadde |
|---|---|---|---|
| **B1** çapraz pim | — | Ø8'den 92 mm kes + 4 oluk | civa çeliği Ø8 |
| **B2** tetik pimi ×2 | — | Ø5'ten 20.7 mm kes + Ø1.5 delik | civa çeliği Ø5 |
| **B7** PTFE burç ×2 | TR'de hazır **YOK** | PTFE çubuktan Ø7 dış / Ø5 iç × 10 mm | PTFE çubuk Ø8-10 |
| **B3** mil bileziği ×2 | tek kaynak **305 TL/ad** | Ø10'dan 6 mm kes, Ø5 del, yandan M3 kılavuz | civa çeliği Ø10 |
| **B5/B6** pimler | fiyat doğrulanamadı | Ø4'ten 4×16 mm, Ø3'ten 2×10 mm kes | civa çeliği Ø4, Ø3 |

**Teknik resim:** `TORNA_IS_EMRI.png` (B1 ve B2 ölçülü). Diğerleri basit kesim.

---

## 📦 SİPARİŞ 1 — MetalAVM (hammadde, tek kargo)
https://metalavm.com · yerli, TR içi kargo, sepet indirimi %2-4

| Ne | Link | Fiyat (2 m tam boy) |
|---|---|---|
| Civa çeliği Ø8 | [metalavm.com/civa-celigi-1-2210-800-mm](https://metalavm.com/civa-celigi-1-2210-800-mm) | ~360 TL + KDV |
| Civa çeliği Ø5 | [civa-celigi-1-2210-500-mm](https://metalavm.com/civa-celigi-1-2210-500-mm) | ~148 TL + KDV |
| Civa çeliği Ø4 | [civa-celigi-1-2210-400-mm](https://metalavm.com/civa-celigi-1-2210-400-mm) | ~120 TL + KDV |
| Civa çeliği Ø3 | [civa-celigi-1-2210-300-mm](https://metalavm.com/civa-celigi-1-2210-300-mm) | ~75 TL + KDV |

**≈ 700 TL + KDV.** ⚠️ Kısa boy satan online satıcı yok; 2 m almak zorundasın
(ucuz, ömür boyu yeter). Mil bileziği için **Ø10 da ekle** istersen.

## 📦 SİPARİŞ 2 — Dalış mağazası (lastik)
| Ne | Satıcı | Link | Fiyat |
|---|---|---|---|
| **O.M.E.R Performer 2 Ø16 metraj** — sayfada *"%100 doğal lateks kauçuk"* ✅ | mertsubonline | [link](https://www.mertsubonline.com/urun/o-m-e-r-performer-2-o16mm-metraj-lastik) | 1.367,80 TL |
| *alternatif* Free-Sub 16mm × 100cm ⚠️ **çift komponentli** (çekirdek doğal, kılıf sentetik) | daliselbisesi | [link](https://daliselbisesi.com/products/free-sub-metraj-zipkin-lastigi-16mm-x-100cm-zipkin-lastik) | 1.113,60 TL |

> **İç çap hiçbir sitede yazmıyor** — ama hesapladım: iç çap ±1 mm bant
> kuvvetini sadece **%4** değiştiriyor. Kritik değil. Kritik olan **dış çap**
> ve **doğal lateks**. İlkini al.

## 📦 SİPARİŞ 3 — avmarketi (iki ip, tek kargo)
| Ne | Link | Fiyat |
|---|---|---|
| DFT Bojin Dyneema **0,16 mm / 9,07 kg / 100 m** ✅ | [link](https://www.avmarketi.com/urun/dft-bojin-dyneema-ip-misina-100-m-0-16-mm-yesil) | 129,51 TL |
| DFT Bojin Dyneema **0,30 mm / 22,67 kg / 100 m** ✅ | [link](https://www.avmarketi.com/urun/dft-bojin-dyneema-ip-misina-100-m-0-30mm-yesil) | 415,32 TL |

## 📦 SİPARİŞ 4 — Robot Sepeti (servo + civata)

> ⚠️ **SERVO SEÇİMİ DEĞİŞTİ.** Aşağıdaki MG996R linki **artık geçerli değil** —
> 110 g gereksiz ağırdı. Makara r=2.2 mm'ye küçültülünce gereken tork
> 2.15 kg·cm'ye düştü ve **mikro metal dişli servo** (~14 g, ≥3.5 kg·cm,
> delik aralığı 28 mm) yetiyor. **−82 g.** Yeni servo için arama gerekli.
| Ne | Link | Fiyat |
|---|---|---|
| Tower Pro MG996R ×2 (11 kg·cm @6V) | [link](https://www.robotsepeti.com/tower-pro-mg996-r-servo-motor-180) | 257,17 ×2 = 514 TL |
| M2×6 imbus DIN912 A2 10'lu | [link](https://www.robotsepeti.com/m2x6-imbus-civata-paslanmaz) | 43,36 TL |
| M2×8 imbus DIN912 A2 10'lu | [link](https://www.robotsepeti.com/m2x8-imbus-civata-10lu) | 37,34 TL |

## 📦 SİPARİŞ 5 — hiber.com.tr (kablolar)
| Ne | Link | Fiyat |
|---|---|---|
| Y-kablo **1 JR erkek → 2 Futaba dişi** 30 cm ✅ | [link](https://www.hiber.com.tr/30-cm-y-tipi-servo-kablosu) | 71,71 TL |
| Servo uzatma 30 cm dişi-erkek | [link](https://www.hiber.com.tr/servo-uzatma-kablosu-30-cm-disi-erkek) | 85,33 TL |

> ⚡ **Y-kabloyu yalnızca SİNYAL için kullan.** İki servonun stall akımı
> 5 A; 22AWG kablo ve alıcı regülatörü yanar. +5V/GND doğrudan BEC'ten.

## 📦 SİPARİŞ 6 — tek kalemlik olanlar
| Ne | Satıcı | Link | Fiyat |
|---|---|---|---|
| M2×3 pirinç insert (Ø3.2 / 3 mm) ✅ **spec %100** | robotizmo | [link](https://www.robotizmo.net/en/insert-cakma-somun-m2-yukseklik-3mm) | 4,71 ×10 = 47 TL |
| Bagaj kantarı 50 kg / 10 g **veri kilitlemeli** | kalitelial | [link](https://kalitelial.com/product/dijital-el-kantari-ve-hassas-valiz-terazisi-50-kg-kapasiteli-termometreli-askili-tarti) | 289 TL |
| Winkel PTFE **kuru** yağlama sprey 400 ml | kulucteknik | [link](https://kulucteknik.com/urun/ptfe-kuru-yaglama-sprey-400ml) | 209 TL |
| Loctite 243 10 ml | yildizburo | [link](https://yildizburo.com) | 515 TL |
| Yay seti 200 parça (içinde 7×12,5 mm var) | worldforce | [link](https://www.worldforce.com.tr/urun/yay-seti-200-parca) | 671,80 TL |
| PTFE çubuk Ø8-10 (20 mm'den kesim) | martanonline | [link](https://martanonline.com/product/ptfe-teflon-cubuk-beyaz/) | 750 TL/kg → ~3 TL malzeme |

> **PTFE'de dikkat:** malzeme bedava sayılır ama **minimum sipariş tutarı**
> olabilir — sipariş öncesi sor.
> **Yay setinde tel çapı hiçbir sayfada yazmıyor** — set gelince kumpasla
> ölç, iç çap ≥5.3 mm olanı seç.

## 🏪 YERELDEN AL — online almak mantıksız
| Ne | Nereden | Neden |
|---|---|---|
| **Kurşun bilye** (aşağıya bak) | Av malzemesi / döküm | ↓ özel durum |
| Talk pudrası | Eczane, bebek pudrası 100-200 g | Online'da 1 kg endüstriyel çuval |
| CA yapıştırıcı | Hırdavatçı/kırtasiye | 35 TL ürüne 60 TL kargo |
| Yapıştırıcı çubuk | Kırtasiye | Aynı |
| **Koruyucu gözlük** | Hırdavatçı, EN166 **F sınıfı** yeterli | **Yüze oturması önemli, dene** |
| **İş eldiveni** | Hırdavatçı, avuç içi deri | **Beden kritik, elle dene** |

### ⚠️ KURŞUN BİLYE — özel durum
Tasarımdaki bilye **Ø12.7 mm kurşun küre = tam 12.16 g**. Piyasada:
- **misket (yuvarlak) seri 8 g'da bitiyor** → 4 g eksik
- **zeytin seri 10/15 g'a çıkıyor** ama **oval** → kapsül yuvasına (Ø12.9) oturmaz

**Çözüm:** **.50 kalibre yuvarlak kurşun** al (tam Ø12.7 mm, karabina/
muzzleloader için satılır) ve **2 mm matkapla kendin del**. Kurşun çok
yumuşak, el matkabıyla 1 dakika. Alternatif: kurşun döküm kalıbı.

---

## 💰 TAHMİNİ TOPLAM

| Grup | Tutar |
|---|---|
| Metal hammadde (MetalAVM) | ~700 TL + KDV |
| Lastik | ~1.370 TL |
| İpler | ~545 TL |
| Servo + civata | ~595 TL |
| Kablolar | ~157 TL |
| Insert + kantar + sprey + Loctite + yay seti | ~1.730 TL |
| PTFE + kurşun + yerel sarf | ~400 TL |
| **ARA TOPLAM** | **~5.500 TL** |
| 3D baskı filament (~190 g PETG) | ~150-250 TL |
| **Torna işçiliği** | **fiyat alınacak** |

> Torna işçiliği için rakam vermiyorum — güncel atölye fiyatlarını
> doğrulayamam. `TORNA_IS_EMRI.png`'yi gösterip teklif al.
> İş ~yarım saat; **malzemeyi sen götür**, onlardan alırsan pahalanır.

## 📋 SİPARİŞ SIRASI (önerilen)
1. **MetalAVM** + **PTFE çubuk** → geldiğinde **tornaya git** (en uzun süren iş)
2. Aynı gün: **lastik**, **ipler**, **servo**, **kablolar** (paralel)
3. 3D baskıları başlat (namlu ~14 saat)
4. Yerel alışveriş: kurşun, talk, CA, gözlük, eldiven
5. Hepsi gelince montaj (`URETIM_MONTAJ_REHBERI.md`)

## ❌ BULUNAMAYANLAR
- **Ø8 7075-T6** → civa çeliğiyle çözüldü (yukarıda)
- **Hazır PTFE burç 5/7×10** → PTFE çubuktan tornada
- **Ø5 mil bileziği** → tek kaynak RS 305 TL/ad, tornada yapılabilir
- **12 g delikli kurşun bilye** → .50 kalibre kurşun + kendin del
- **Tam metal dişli MG996R** → r=4 makarayla gerek kalmadı

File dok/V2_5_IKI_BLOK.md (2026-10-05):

# v2.5 — Kapsül iki bloğa ayrıldı

## Sorun

Kapsül tek parçaydı ve esnek bandı taşıyan **çapraz pim** kapsülün arka
bloğundan geçiyordu. Bant pimi ileri doğru itiyor, ama pim yarık içinde
hareket ediyor ve **yarığın sonunda duruyor** — yani kapsülün gidebileceği
yolu bant/pim/yarık üçlüsü sınırlıyor. Kapsülün ağzı namlu ağzındaki omza
çarpmak zorunda; ikisi aynı parçada olduğu için ya pim yarığın sonuna
çarpıyor ya kapsül omza, hangisi önce gelirse.

## Çözüm

Kapsül yerel **y = 16.0 mm** düzleminden (arka bloğun üst yüzü) ikiye
bölündü:

| Blok | Ne taşıyor | Hacim | Kütle | Durduran |
|---|---|---|---|---|
| **02a_kapsul_alt** | çapraz pim, tutma kanalı, kurma deliği, hizalama spigotu | 33.75 cm³ | 35.1 g | yarık sonu TPU tamponu |
| **02b_kapsul_ust** | ağ haznesi, boncuk başlığı, 6 × yuva | 45.74 cm³ | 47.6 g | namlu ağzı omzu |

Alt blok üst bloğu **iter**, birbirine bağlı değiller. Alt blok yarık
sonunda durduğunda üst blok **serbest kalır** ve kendi atalet hızıyla
gidip omza çarpar.

### İtme yüzeyi

İtme spigottan değil, alt bloğun **tam halka yüzünden** geçiyor:

```
R_hazne 24.1 .. R_kapsül 31.6  →  594 mm²
PETG 50 MPa  →  29.712 N taşır
```

Gerekli itme kuvveti tam kurmada 391 N. Marj **76×**.

### Hizalama spigotu

Alt bloğun üstünde **cidar kalınlığı 2.5 mm**, yüksekliği **6 mm** bir
boru var; üst bloğun haznesine 0.4 mm boşlukla giriyor. İşi sadece iki
bloğu eş eksende tutmak — yük taşımıyor. Hazneden ~15 cm³ yiyor,
ağ için **~42 cm³** kalıyor (doluluk %26).

### Durdurma enerjisi bölündü

Eskiden tek stop (omuz) her şeyi durduruyordu. Şimdi:

```
v = 17.4 m/s
  alt blok + çapraz pim   50.3 g  →   7.6 J   (yarık sonu TPU tamponu)
  üst blok + ağ + boncuk  81.2 g  →  12.3 J   (namlu omzu, 295 mm²)
```

Omzun yükü ~15 J'den **12.3 J'ye** indi. 2 mm TPU 95A halka
(20 MPa, %60 ezilme) 7.1 J yutuyor; kalan 5.2 J / 14.744 N = **0.35 mm**
ezilme. Eskiden 1.19 mm'ydi.

## Ayrılma mesafesi — ayarlanacak

CAD'de alt bloğu durduran **geometrik** bir engel yok: çapraz pim
y=100.5'e kadar geliyor, omuz halkasının kulakları y=128.83'te başlıyor,
bant o noktada tam olarak serbest boyunda. Yani **alt bloğun nerede
durduğunu yarık sonundaki TPU tamponun kalınlığı belirliyor.**

Şu anki 3 mm tamponla iki blok **birlikte** varıyor — ayrılma olmuyor,
ama darbe yine iki stop arasında **paylaşılıyor** (kazanç bu).

Gerçek ayrılma istiyorsan tamponu kalınlaştır:

| Tampon | Alt blok erken durur | Üst blok serbest yolu | Strok | Enerji |
|---|---|---|---|---|
| 3 mm (şimdiki) | — | 0 mm | 91 mm | %100 |
| 8 mm | 5 mm | 5 mm | 86 mm | %95 |
| 13 mm | 10 mm | 10 mm | 81 mm | %89 |

Bedeli: strok kısalır → λ düşer → enerji düşer. **10 mm ayrılma için
%11 enerji** veriyorsun. İlk testte 3 mm ile başla, iki blok birlikte
gitsin; pim/yarık kırılma belirtisi görürsen tamponu kalınlaştır.

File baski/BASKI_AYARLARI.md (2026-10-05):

# 3D BASKI AYARLARI — Ağ Fırlatıcı v5

Bu klasördeki **8 parça** 3D yazıcıdan çıkacak. Satın alınan parçalar
(kurşun bilye, alüminyum çapraz pim, lateks tüp, çelik tetik pimi, servo…)
burada **yok** — onlar `malzeme_listesi.md`'de.

> **STL'ler slicer'a hazır yöndedir.** Tablaya oturtulmuş, XY'de ortalanmış.
> **Döndürme. Sadece sürükle-bırak.** Yön kritik (bkz. §2).

---

> **v2.0 — NAMLU Ø43.4 → Ø55.0 BÜYÜDÜ. HER ŞEY YENİDEN BASILACAK.**
>
> İstenen mimari: **ağ haznede, boncuklar kapsülün ağzında.** Kapsül namlu
> ağzına çarpınca önce boncuklar fırlar, ağı arkalarından çeker.
> Bu, Ø43.4'te geometrik olarak mümkün değildi (ağ geçişi Ø10.8'de kalıyordu);
> 6 yuvanın çevrede 74.4 mm yer istemesi bunu dayatıyor.
>
> | | Ø43.4 (v1.5) | **Ø55.0 (v2.0)** |
> |---|---|---|
> | Ağ geçişi | Ø10.8 / 97 mm² | **Ø18.6 / 271 mm²** |
> | Hazne doluluğu | %51 (zor) | **%31 (rahat)** |
> | Yuva boşluğu | 0.4 mm (çok sıkı) | **0.8 mm** |
> | Tutma dudağı sıkması | 0.4 mm | **0.2 mm** |
> | Omuz | 282 mm² | **300 mm²** |
> | Mesafe (0.45 MPa) | 0.78–0.97 m | 0.62–0.90 m |
>
> Bedeli: kapsül 44 → 71 g, baskı 214 → 280 g, menzil ~%10 kısa.
> Kapsül **AĞIZ YUKARI** basılır. Ayrıntı: `out/V2_0.md`.

## 1. PARÇA LİSTESİ

| Dosya | Parça | Adet | Filament | Ölçü (X×Y×Z mm) | Filament |
|---|---|---|---|---|---|
| `01a_namlu_govde` | Namlu gövdesi (arka parça) | 1 | **PETG** | 109 × 100 × **142.0** | ~178.2 g |
| `01b_agiz_basligi` | Ağız başlığı (ıraksak koni) | 1 | **PETG** | 92 × 128 × **21.5** | ~56.1 g |
| `02_kapsul` | Kapsül | 1 | **PETG** | 63 × 63 × **41.0** | ~74.4 g |
| `03_tetik_kapagi_sag` | Tetik kartuş kapağı (sağ) | 1 | **PETG** | 18 × 18 × **3.0** | ~0.9 g |
| `04_tetik_kapagi_sol` | Tetik kartuş kapağı (sol) | 1 | **PETG** | 18 × 18 × **3.0** | ~0.9 g |
| `05_servo_makarasi` | Servo ip makarası | **2** | **PETG** | 10 × 10 × **6.4** | ~0.8 g |
| `06_toz_kapagi` | Arka toz kapağı (opsiyonel) | 1 | **PETG** | 69 × 69 × **6.0** | ~13.7 g |
| `07_tampon_ust` | Yarık sonu tamponu (üst) | 1 | **TPU 95A** | 9 × 7 × **3.0** | ~0.1 g |
| `08_tampon_alt` | Yarık sonu tamponu (alt) | 1 | **TPU 95A** | 9 × 7 × **3.0** | ~0.1 g |
| `10_takoz_pad` | 10_takoz_pad | **2** | **TPU 95A** | 9 × 14 × **4.9** | ~3.0 g |

**TOPLAM: PETG ~325 g · TPU ~3.2 g**

Her parça hem `.stl` (baskı) hem `.step` (CAD, ölçü almak/değiştirmek için)
olarak var. Ölçüler `parcalar.json`'da.

### Yazıcı şartı
**Z yüksekliği ≥ 147 mm** gerekli (en uzun parça 142.0 mm).
Tabla ≥ 110 × 110 mm. Ender 3 / Prusa MK3 / Bambu P1 sınıfı yeterli.

---

## 1.5 ⚠️ DESTEK — İLK BASKIDA HATA ALINDI, OKU

**Bu bölüm bir baskı denemesinden sonra düzeltildi.** İlk sürümde
"destek: YOK" yazıyordu; bu **yanlıştı** ve namlu deliğinin destek
malzemesiyle dolmasına yol açtı.

### Gerçek durum (STL'den ölçüldü)
Namlu yüzeyinin **%2.4'ü (1397 mm²)** 45°'den dik aşağı bakıyor ve
destek ister:
* **tetik kartuş göbekleri** — Ø18 mm YATAY silindir, z ≈ 133 mm'de
  havada başlıyor
* **servo yatakları** — 4 × 36 mm plaka, z ≈ 103 mm, yatay çıkıntı

Bant ankraj kulakları tabanda (z = 0), onlara destek **gerekmez**.

### Ama desteği öylece açarsan NAMLU DELİĞİ DOLAR
Namlu, ağzı AŞAĞI basılır; yani Ø43 delik **tabana açıktır**. Dilimleyici
"her yerde destek" ya da "sadece tabladan destek" ile bu deliği de
doldurur — delik içine ince duvarlar örer. Parça dışarıdan doğru görünür
ama **içi dolu çıkar**.

### DOĞRU AYAR
```
destek            : AÇIK  (tetik göbekleri + servo yatakları için)
destek açısı eşiği: 45°
+ NAMLU DELİĞİNE DESTEK ENGELLEYİCİ KOY        ← ŞART
```
| Dilimleyici | Nasıl |
|---|---|
| **PrusaSlicer** | Sağ tık → *Add support blocker* → silindir, Ø45 × 150 mm, deliğin içine |
| **Cura** | *Support Blocker* küpü ekle, Ø43 deliği kaplayacak şekilde ölçekle |
| **Bambu Studio / Orca** | *Support painting* → **Block** fırçası ile deliğin iç yüzeyini boya |

**Alternatif (en basit):** desteği tamamen KAPAT. Göbeklerin ve servo
yataklarının alt yüzeyi bir miktar sarkar ama bunlar kritik yüzey
değildir — göbekteki Ø5 delik zaten matkapla raybalanıyor, servo yatağı
da düz oturur. Delik temiz kalır, parça kullanılabilir.

> **Elindeki baskı muhtemelen kurtarılabilir:** delikteki destek
> malzemesi KOPARILABİLİR. Uzun bir pense/tornavida ile içeriden sök,
> sonra Ø43'lük bir boru veya zımpara çubuğuyla temizle. Kapsül serbest
> kayıyorsa parça kullanılır.

---

## 2. NEDEN BU YÖN — namluyu YATAY basma

Namlu kurulduğunda bant kulaklarına **toplam ~1200 N** çekme gelir.

* **Dik basılırsa** (bu klasördeki STL): kuvvet katman düzlemine **paralel**
  olur. Yük, filamentin kendi mukavemetiyle taşınır.
  **STL'de namlu AĞZI AŞAĞI, dibi yukarıdadır** — bant ankraj kulakları
  (Ø104 mm) tablada oturur, geniş ve sağlam bir taban verir. (Önceki
  sürümde "ağız yukarı" yazıyordu, yanlıştı.)
* **Yatay basılırsa**: kuvvet katmanları **ayırmaya** çalışır. FDM'de
  katmanlar arası dayanım, katman içi dayanımın **%40-60'ıdır**.
  Kulak kopar.

Bu pazarlık konusu değil. Aynı mantık kapsül için de geçerli: arka blok
16 mm boyunca 1200 N'u çapraz pime aktarır.

---

## 3. PETG AYARLARI

### 3.1 Ortak (tüm PETG parçalar)
```
nozzle çapı        : 0.4 mm
nozzle sıcaklığı   : 240 °C   (ilk katman 245 °C)
tabla sıcaklığı    : 80 °C
katman yüksekliği  : 0.20 mm
ilk katman         : 0.25 mm, %50 hız
hız                : 45 mm/s  (dış duvar 25 mm/s)
soğutma            : %30      ← PETG'de fazla fan katman yapışmasını BOZAR
retraction         : 4 mm @ 35 mm/s  (direct drive: 1.5 mm)
z-hop              : 0.2 mm   (PETG sicim yapar)
```

### 3.2 Parça bazlı

**`01_namlu` — en kritik parça (~12 saat)**
```
duvar (perimeter)  : 4 çevre     → 1.6 mm katı kabuk
üst/alt katman     : 5
dolgu              : %50 gyroid
destek             : YOK
brim               : 5 mm        ← 180 mm yüksek, devrilmesin
```
> %50'nin altına inme — bant kulakları ve tetik göbekleri dolguya oturuyor.

**`02_kapsul` (~3 saat)**
```
duvar              : 5 çevre
üst/alt            : 5
dolgu              : %60 gyroid
destek             : YOK
```
> Bilye yuvaları 13° konik — overhang değil, destek istemez.

**`03`/`04` tetik kapağı, `05` servo makarası**
```
katman             : 0.15 mm   (delik hassasiyeti için)
duvar              : 3 çevre
dolgu              : %100
destek             : YOK
```
> Küçük parçalar: ikisini/dördünü aynı anda bas, soğuma süresi artsın.

**`06` toz kapağı (opsiyonel)**
```
duvar              : 3 çevre,  dolgu %20,  destek YOK
```

---

## 4. TPU 95A AYARLARI (`07`, `08`)

```
nozzle             : 230 °C
tabla              : 50 °C
katman             : 0.20 mm
hız                : 20 mm/s     ← YAVAŞ, TPU hızda kaçırır
dolgu              : %30
duvar              : 2 çevre
retraction         : KAPALI      ← TPU'da retraction tıkanma yapar
soğutma            : %50
```
> İkisi birlikte 10 dakikada biter. Bowden ekstruderle zorlanırsan
> hızı 12 mm/s'ye düşür.

---

## 5. BASKI SONRASI İŞLEMLER

Sırayla yap:

1. **Namlu yarıklarını temizle** — iki düz yarık (9.4 mm) eğeyle açılsın.
   Kapsülün çapraz pimi buradan geçecek, takılma olmamalı.

2. **Tetik pimi deliklerini raybala** — 5.0 mm matkapla geç, sonra
   **PTFE burcu (B7)** çak.

3. **M2 ısıl insertleri otur** — 8 adet (4 kapak + 4 servo).
   Havya 220 °C, dik tut, yavaş bastır. Eğri girerse vida tutmaz.

4. **Kapsül–namlu uyumunu test et** — kapsülü namluya **boş** sok.
   Kendi ağırlığıyla kaymalı. Takılıyorsa kapsül dış çapını
   zımparala (hedef boşluk 0.3 mm).

5. **Tamponları yapıştır** — TPU tamponları yarıkların **ön ucuna**
   CA ile. Kapsülün çarpma yükünü (~450 N) bunlar yumuşatacak.

### KONTROL — geçmeden montaja başlama
- [ ] Kapsül namluda serbest kayıyor
- [ ] Tetik pimleri burçlarda pürüzsüz hareket ediyor
- [ ] 8 insert dik oturmuş, M2 vida tutuyor
- [ ] Namlu kulaklarında katman ayrışması / çatlak yok
- [ ] Tamponlar yarık ucunda sağlam

---

## 6. FİLAMENT SEÇİMİ

| | Öneri | Neden |
|---|---|---|
| **PETG** | Standart PETG yeterli | Tok, katmanlar iyi kaynaşır, 80 °C'ye dayanır |
| **ASA** (daha iyi) | Dışarıda kalacaksa | UV dayanımı. Ama kapalı kabin ister, çeker |
| **PLA** | **KULLANMA** | Kırılgan; 1200 N çekme altında ani kırılır. Güneşte 50 °C'de yumuşar |
| **ABS** | Gerekmez | PETG'den avantajı yok, baskısı zor |
| **TPU 95A** | Tampon için şart | 85A çok yumuşak, 98A çok sert |

> **PLA uyarısı ciddi.** Bu parça kurulduğunda 120 kg depoluyor ve
> güneş altında bekleyecek. PLA'da kulak kopması zaman meselesidir.

---

## 7. YEDEK BAS

İlk denemede kırılması muhtemel parçalar:
- **tetik kapağı** ×2 fazladan (ince, M2 deliği yırtılabilir)
- **servo makarası** ×2 fazladan (servo kolu markaya göre değişir, ölçü tutmayabilir)
- **tampon** ×2 fazladan (her atışta eziliyor)

Namlu ve kapsülü yedeklemek pahalı; onun yerine **ayarları doğrula**
(§5 kontrol listesi) ve bir kez doğru bas.

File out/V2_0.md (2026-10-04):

# v2.0 — İSTENEN MİMARİ: AĞ HAZNEDE, BONCUKLAR AĞIZDA

> **Ağ haznenin içinde olmalı, boncuklar kapsülün ağzında olmalı, kapsül
> namlu ağzına çarptığı anda boncuklar fırlamalı, arkasından ağı çekmeli.**

Bu kuruldu. Bedeli: **namlu Ø43.4 → Ø55.0.**

---

## 1. NEDEN NAMLU BÜYÜMEK ZORUNDAYDI

6 boncuk yuvası ağız çevresinde **74.4 mm** yer istiyor (Ø9.6 bore +
2 × 1.4 mm cidar). Bu sayı küçültülemez — boncuk Ø8.80.

Yuvalar 40° eğimli olduğu için ağız düzleminde **elips** kesit verirler;
radyal yarı-eksenleri 6.2 değil **8.09 mm**. Ortada ağa kalan alan
`π·(R_pitch − 8.09)²`, ve R_pitch kapsül cidarıyla sınırlı.

| Namlu içi | R_pitch sınırı | Ağ geçişi | Hazne doluluğu |
|---|---|---|---|
| Ø43.4 | 13.4 | **Ø10.8 (97 mm²)** | %51 — ağ zor giriyor |
| **Ø55.0** | **18.2** | **Ø18.6 (271 mm²)** | **%31 — rahat** |

Ø43.4'te 97 mm² mutlak tavandı. İstenen mimari o çapta kurulamıyordu.

## 2. YUVALAR GENİŞLETİLDİ

Baskıda boncuklar zar zor giriyordu — haklı şikâyet:

| | eski | **yeni** |
|---|---|---|
| Yuva çapı | Ø9.2 | **Ø9.6** |
| Boncuk boşluğu | 0.4 mm | **0.8 mm** |
| Tutma dudağı | Ø8.40 | **Ø8.60** |
| Dudak sıkması | 0.4 mm | **0.2 mm** |
| Yuva derinliği | 7.0 mm | **7.5 mm** |

Dudak hâlâ boncuğu tutuyor (Ø8.60 < Ø8.80) ama elle bastırınca giriyor.

## 3. ÇALIŞMA SIRASI

1. Kapsül namlu ağzındaki omza çarpar ve **durur**
2. Boncuklar ataletle devam eder, 40°'lik yuvalardan **dışa doğru fırlar**
3. Boncukların önünde **hiçbir şey yoktur**
4. Ağ, köşelerinden **çekilerek** Ø18.6 geçişten hazneden çıkar

Gerçek ağ tabancalarının düzeni budur: **ağırlık önde, ağ arkada.**

## 4. DOĞRULAMA

`cad/kontrol_omuz.py`, `kontrol_ankraj.py` ve ağız düzlemi taraması:

| | |
|---|---|
| Merkezi bağlı boş alan | **271 mm² (Ø18.6)** — 161×161 ızgara taraması |
| Hazne hacmi | 35.9 cm³ · ağ ipi 11.1 cm³ → **%31** |
| Durdurma omzu | **300 mm² → 14.989 N** |
| Boncuk/koni payı | omuzda +2.68 mm, ağızda +1.00 mm |
| Anti-çakışma | arka boncuk ekseni 15.37 mm (≥9 gerekli) |
| Bant ankrajı payı | +4.28 mm |

### Yolda yakalanan hata
İlk denemede merkezi geçişin duvarını boru dış yüzeyine **tam teğet**
yapmıştım (ikisi de R10.11). Sıfır kalınlıkta temas booleanı bozdu: katı
`gecerli=False` çıktı ve ağız kesiti 0 mm² ölçüldü. `t_ara = 0.8 mm`
gerçek cidar eklendi.

## 5. SONUÇ

| Gmod | kurma | v_çıkış | ağ çapı | pay | mesafe |
|---|---|---|---|---|---|
| 0.25 MPa | 261 N (27 kg) | 14.8 m/s | 1.78 m | 1.04× | 0.39–0.76 m |
| 0.35 MPa | 365 N (37 kg) | 17.6 m/s | 1.85 m | 1.08× | 0.50–0.84 m |
| **0.45 MPa** | **470 N (48 kg)** | **19.9 m/s** | **1.90 m** | **1.11×** | **0.62–0.90 m** |
| 0.55 MPa | 574 N (58 kg) | 22.1 m/s | 1.94 m | 1.13× | 0.73–0.95 m |
| 0.65 MPa | 678 N (69 kg) | 24.0 m/s | 1.97 m | 1.14× | 0.83–0.99 m |

Her sertlikte ağ açılıyor (pay ≥ 1.04×).

## 6. BEDELİ — AÇIKÇA

| | v1.5 (Ø43.4) | **v2.0 (Ø55.0)** |
|---|---|---|
| Kapsül | 44 g | **71 g** |
| Duracak kütle | 56 g | **84 g** |
| Baskı filamenti | 214 g | **281 g** |
| Fırlatıcı toplam | ~350 g | **~436 g** |
| Namlu dış çapı | Ø55.4 | **Ø67** |
| Mesafe (0.45 MPa) | 0.78–0.97 m | 0.62–0.90 m |

Menzil ~%10 kısaldı (kapsül ağırlaştı). Tail-sitter'a asılacak yük %25 arttı.

**Her parça yeniden basılacak** — namlu gövdesi dahil.

## 7. DURDURMA ENERJİSİ

Duracak kütle 84.3 g:

| v_çıkış | enerji | TPU yutar | kalan elastik | tepe kuvvet |
|---|---|---|---|---|
| 16 m/s | 10.8 J | 7.2 J | 0.24 mm | 14.989 N |
| 20 m/s | 16.9 J | 7.2 J | 0.64 mm | 14.989 N |
| 24 m/s | 24.3 J | 7.2 J | 1.14 mm | 14.989 N |

Omuz 300 mm² olduğu için 24 m/s'de bile tepe kuvvet sınırın altında.

Test merdiveni yine geçerli: ilk atış **1 bant + 40 mm çekiş**.

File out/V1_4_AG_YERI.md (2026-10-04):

# v1.4 — AĞ ARTIK NAMLUDA, KAPSÜLÜN ÖNÜNDE

Render'da gördüğün şey doğruydu: **ağın çıkacağı yer kalmamıştı.**

---

## 1. ÖLÇÜLEN SORUN

6 boncuk borusu, 40° eğimli olduğu için ağız düzleminde elips kesit veriyor
(radyal yarı-ekseni 6.0 değil **7.83 mm**). R12 bölüm dairesinde 6 boru,
75.4 mm'lik çevrenin 72 mm'sini kaplıyor. Geriye kalan:

| | |
|---|---|
| Merkezdeki boş daire | **55 mm² (Ø8.3 eşdeğeri)** |
| Borular arası boşluk | 6 × 0.57 mm |
| Geçmesi gereken | 39.2 m ip = 11.1 cm³ |

**39 metre ipin Ø8 delikten geçmesi mümkün değil.**

## 2. BU BİR AYAR HATASI DEĞİL, MİMARİ ÇIKMAZ

Durdurma omzunun ≥250 mm² olması için namlu konisinin başlangıcı
R_om ≤ 19.34 olmalı. R_om = R_pitch + 7.08 olduğundan **R_pitch ≤ 12.26**.

R_pitch'i 12.26'ya kadar açsan bile merkezdeki boş daire **62 mm²**.

> **Durdurma omzu ile merkezi ağ çıkışı aynı kapsülde bir arada olamaz.**

R_pitch'i büyütmek omzu yok ediyor (R_pitch 15.3'te omuz sıfır), küçültmek
ağ çıkışını yok ediyor. Arada çözüm yok.

## 3. ÇÖZÜM: AĞ NAMLUYA

Ağ kapsülün içinden değil, **namlunun içinden, kapsülün önünden** çıkıyor.
Kapsül bir **piston**: ağı iterek dışarı çıkarıyor. Boncuklar yine kapsülün
yuvalarında ve 40° ile fırlıyor; iplerini önlerindeki ağa bağlıyorlar.

| | kapsül içinde (eski) | **namluda (yeni)** |
|---|---|---|
| Ağ için hacim | 22.1 cm³ | **134.6 cm³** |
| Doluluk | %75 (sıkışık) | **%8 (bol)** |
| Çıkış kesiti | 55 mm² (Ø8.3) | **tüm namlu Ø43.4** |
| Sıkışma riski | yüksek | yok |

Bu, ticari ağ tabancalarının da yaptığı şey — sabot ağı iter.

### Kapsülde ne değişti
- **Başlık artık MASİF.** Ağ geçmeyeceği için merkezi delik tamamen kaldırıldı:
  daha güçlü, takılacak çıkıntı yok.
- İç boşluk sadece **ağırlık azaltma** için, koni biçiminde ve kapalı
  (ağız yukarı basımda tavan yok, destek gerekmiyor).
- Boncuk yuvaları aynı: kapalı taban, Ø8.40 tutma dudağı, Ø3 ip/hava deliği.

### Bedeli
Kapsül 43.8 → **51.4 g** (başlık masifleşti). Çıkış hızı 23.1 → 22.0 m/s,
mesafe 0.78–0.97 → **0.73–0.95 m**. Küçük kayıp, karşılığında ağ gerçekten
çıkabiliyor.

---

## 4. YÜKLEME SIRASI DEĞİŞTİ

1. Ağı **namlunun ağzından** içeri, gevşek katlar halinde yerleştir.
   91 mm'lik strok boyunca yayılsın (çok yer var, sıkıştırma).
2. Boncukları kapsülün yuvalarına **bastırarak** oturt (dudak tutar).
   Her boncuğun ipi yuvanın ağzından öne, ağa gider.
   Durdurma düğümü boncuğun **arkasında**, yuvanın dibinde kalır.
3. Kapsülü namluya sok, çapraz pimi tak.
4. Kapsülü geri çek, tetik pimlerini sok.
5. Namlu ağzına **kırılgan ön kapak** (ince kağıt disk) yapıştır — ağ
   namluda serbest durduğu için, fırlatıcı aşağı bakarken dökülmesin.
   *(Malzeme listesinde F5)*

**Ön kapak artık opsiyonel değil, gerekli.**

---

## 5. SONUÇ

| Gmod | kurma | v_çıkış | ağ çapı | pay | mesafe |
|---|---|---|---|---|---|
| 0.25 MPa | 261 N (27 kg) | 16.4 m/s | 1.82 m | 1.06× | 0.44–0.81 m |
| 0.35 MPa | 365 N (37 kg) | 19.4 m/s | 1.89 m | 1.10× | 0.60–0.89 m |
| **0.45 MPa** | **470 N (48 kg)** | **22.0 m/s** | **1.94 m** | **1.13×** | **0.73–0.95 m** |
| 0.55 MPa | 574 N (58 kg) | 24.4 m/s | 1.97 m | 1.15× | 0.84–0.99 m |
| 0.65 MPa | 678 N (69 kg) | 26.5 m/s | 2.00 m | 1.16× | 0.86–1.03 m |

## 6. DİKKAT: DURDURMA ENERJİSİ ARTTI

Kapsül ağırlaştığı için duracak kütle **63.3 g**:

| v_çıkış | durdurulacak enerji | omuz (282 mm², TPU 2 mm) |
|---|---|---|
| 16.4 m/s | 8.5 J | rahat |
| 22.0 m/s | 15.3 J | tamam (tepe 14.092 N) |
| 26.5 m/s | 22.2 J | **sınırda** |

Bant ölçümü **0.55 MPa'nın üstü** çıkarsa tam gerdirme yapma; ya 1 bantla
git ya da omuz halkasını **iki kat** (2 × 2 mm TPU) koy.

Test merdiveni yine geçerli: ilk atış **1 bant + 40 mm çekiş**.

---

# EK: `02b_kapsul_hazneli` — AĞ İÇERİDE VARYANTI

Ağı kapsülün içinde taşıyan ikinci bir kapsül de üretildi. Boncuk
düzeltmeleri (kapalı yuva dibi, Ø8.40 tutma dudağı, Ø3 ip deliği, 40°
fırlatma açısı) **ikisinde de aynı** — tek fark haznenin ve merkezi ağ
çıkışının olması.

## Ağ çıkışı nasıl 1.7× büyütüldü

Boncuk bölüm dairesi, kapsül cidarının izin verdiği **en dışa** itildi:
R_pitch 12.0 → **13.4**. O noktada borunun dış kenarı 21.23 mm
(cidar 21.30 — tam sınır) ve merkezde ağa kalan alan:

| | v1.3 (R12.0) | **02b (R13.4)** |
|---|---|---|
| Merkezi bağlı boş alan | 55 mm² | **92 mm² (Ø10.8)** |

Ölçüm analitik değil: ağız düzlemi 161×161 ızgarayla tarandı ve eksenden
başlayan **bağlı** boşluk bölgesi sayıldı. (`02`'de bu alan 0 mm² — başlık
masif, amaçlandığı gibi.)

**Namlu başlığı değişmiyor:** boncukların dış kenarı 13.4 + 4.4 = 17.80 mm,
ıraksak koni 19.08'de başlıyor. Aynı namlu her iki kapsülle de çalışır.

## Karşılaştırma

| | `02_kapsul` | `02b_kapsul_hazneli` |
|---|---|---|
| Ağ nerede | namluda, kapsülün önünde | kapsülün içinde |
| Ağ hacmi | 134.6 cm³ (%8 dolu) | 21.6 cm³ (%51 dolu) |
| Ağ çıkış kesiti | — (gerekmiyor) | **Ø10.8 / 92 mm²** |
| Kapsül kütlesi | 51.4 g | **44.3 g** |
| Duracak kütle | 63.3 g | **56.2 g** |
| Omuz temas alanı | 282 mm² | 282 mm² |
| v_çıkış (0.45 MPa) | 22.0 m/s | **23.0 m/s** |
| Mesafe (0.45 MPa) | 0.73–0.95 m | **0.78–0.97 m** |
| Ön kapak | **şart** | gerekmez |

## DÜZELTME: 02b ÖNERİLMİYOR

Render karşılaştırması gösterdi ki 02b'nin ağzı da pratikte kapalı:
92 mm², yani **1425 mm²'lik ağzın %6.5'i**. "Ağ çıkışı" demek yanıltıcı.

**Neden daha iyisi yapılamıyor:** 6 boncuk yuvası ağız çevresinde
**72 mm** yer istiyor (Ø9.2 bore + 2×1.4 cidar, küçültülemez).

| R_pitch | çevre | yuvaların kapladığı |
|---|---|---|
| 12.0 | 75.4 mm | %95 |
| **13.4** (sınır) | 84.2 mm | **%86** |
| 17.8 | 111.8 mm | %64 |

R_pitch'i büyütmek kapsülü büyütmeyi gerektiriyor. **Ø43.4 namluda
92 mm² mutlak tavandır.**

### Ağ gerçekten kapsülün içinde olacaksa namlu büyümeli

Merkezde Ø20 (314 mm²) ve omuzda 250 mm² için:

| | şimdi | gerekli |
|---|---|---|
| R_pitch | 13.4 | **17.8** |
| Kapsül çapı | Ø42.6 | **Ø53.3** |
| Namlu iç çapı | Ø43.4 | **Ø54.1** |
| Namlu dış çapı | Ø55.4 | ~Ø66 |

Bu, namlunun ve tüm fırlatıcının yeniden boyutlandırılması demek.

## Önerim

**`02` bas.** `02b` sadece karşılaştırma için dursun — ağ oradan geçmez.
Ağı kapsül içinde isteyen bir sürüm gerçekten gerekiyorsa, doğru yol
namluyu Ø54'e büyütmek; söyle, o varyantı kurayım.

Test merdivenine uy: ilk atış **1 bant + 40 mm çekiş**.

---

# DÜZELTME 2 — ÖNERİ TERSİNE ÇEVRİLDİ: `02b` KULLAN

Kullanıcı sordu: *"ağ bilyelerin önünde olursa, bilyeler ağın etrafına değil
içinden geçip ağı birbirine geçirmez mi?"* — **Haklı. `02` önermem hataydı.**

## Ölçülen risk

`02`'de kapsül namlu ağzında durduğu anda boncuklar çıkıyor; yani
**boncukların başlangıç noktası ağın arka yüzüyle aynı düzlem.**

| | |
|---|---|
| Boncuk radyal hızı | 18.5 m/s |
| R12'den namlu cidarına | 9.7 mm |
| Ağ demetinden çıkma süresi | **0.53 ms** |
| O sürede eksende ilerleme | **11.6 mm** |
| O dilimdeki iplik | **~5.0 m** |
| Dilimin hacimce doluluğu | %8 |
| Boncuk Ø8.8 vs göz 220 mm | gözden rahat geçer |

Her boncuk ~5 m iplik içeren bir dilimi radyal olarak yarıyor. Seyrek olsa
bile 6 boncuğun hiçbirinin takılmaması şans işi.

## Doğru sıralama

Gerçek ağ tabancaları **ağırlığı önde** fırlatır; ağ arkadan, köşelerinden
**çekilerek** açılır. `02b` bu düzende: boncuklar önce çıkar, önlerinde
hiçbir şey yoktur.

## Kalan sorun ve açı takası

`02b`'nin boğazı Ø10.8. Yuva açısını düşürmek boğazı büyütüyor ama açılma
payını düşürüyor:

| yuva açısı | R_pitch sınırı | boğaz | pay 0.25 MPa | pay 0.45 | pay 0.65 |
|---|---|---|---|---|---|
| 25° | 14.61 | Ø16.0 (201 mm²) | 0.82× ✗ | 0.89× ✗ | 0.93× ✗ |
| 30° | 14.30 | Ø14.7 (171 mm²) | 0.91× ✗ | 0.99× ✗ | 1.03× |
| **35°** | 13.91 | **Ø13.2 (136 mm²)** | 1.00× ✗ | **1.07×** | **1.10×** |
| **40° (şimdiki)** | 13.40 | Ø11.1 (97 mm²) | **1.07×** | **1.14×** | **1.17×** |

**Karar bant ölçümüne bağlı:**
- Bant **0.35 MPa'nın altı** çıkarsa → 40°'de kal (boğaz dar ama ağ açılır)
- Bant **0.35 MPa ve üstü** çıkarsa → **35°'ye in**, boğaz Ø11.1 → **Ø13.2**
  (%40 daha geniş kesit), pay 1.07× ile hâlâ güvenli

Ölçümü yap, söyle — 35°'lik kapsülü çıkarırım.

## Ağı nasıl paketle

Boğaz dar olduğu için paketleme yöntemi kritik:
- **Katlı** paketle, rastgele tıkma (paraşüt torbası mantığı)
- Köşeler (boncuklu uçlar) **en dışta/en önde** olsun — ilk onlar çekilecek
- İpler birbirinin üstünden geçmesin; akordeon gibi katla

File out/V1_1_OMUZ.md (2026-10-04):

# v1.1 — DURDURMA OMUZU

v1 ile aynı: namlu 149.8 mm · strok 91 · L0 30.3 · koni 40° · 6 boncuk · 2 bant.
**Tek değişiklik: kapsülü ne durduracağı.**

---

## 1. SORUN

Kapsül namludan **çıkmıyor**; namlu içinde durması gerekiyor.
Duracak kütle = kapsül 35.5 g + çapraz pim 11.9 g = **47.4 g**.
Tam gerdirilmiş 2 bantla çıkış hızı 23.2 m/s → **12.8 J durdurulacak enerji**.

v1'de bunu durduran tek şey **Ø8 çapraz pimin yarık ucuna çarpması**:
temas alanı 96 mm², PETG'in taşıyabileceği azami kuvvet 4.800 N.
3 mm'lik TPU tampon ancak 3.5 J yutuyor. **Tam gerdirilirse yarık ucu kırılır.**

## 2. "SERTÇE ÇARPSIN" NEDEN OLMAZ

Enerji yok olmuyor, bir yere gitmek zorunda: **F × d = E**.
Durma mesafesi kısaldıkça kuvvet büyür.

| durma mesafesi | kuvvet (12.8 J için) |
|---|---|
| 0.2 mm (sert PETG-PETG) | **64.000 N ≈ 6.5 ton** |
| 1.2 mm (TPU ezilmesi) | 10.700 N |
| 5 mm | 2.560 N |

Saf PETG-PETG çarpmayı elastik olarak da hesapladım: temas rijitliği
`k = EA/L ≈ 6.1×10⁷ N/m`, `F = √(2kE) = 39.800 N` → **132 MPa**.
PETG 50 MPa'da kırılır. **Uyumlu katman şart** — enerjiyi "yutmak" için değil,
durmayı uzatıp kuvvet tepesini düşürmek için.

## 3. ÇÖZÜM: OMUZ + BONCUK ÇEMBERİNİ KÜÇÜLTME

Namlu ağzına içe doğru tam daire bir omuz; kapsülün halka kenarı ona oturuyor.
**Ama bu, boncuk çemberi küçülmeden anlamsız:**

| R_pitch | boncuk dış kenarı | omuz iç R | halka alanı | F_max |
|---|---|---|---|---|
| 15.5 (v1) | 20.0 | 21.0 | **74 mm²** | 3.676 N ← pimden kötü |
| 13.0 | 17.5 | 20.2 | 180 mm² | 8.992 N |
| **12.0** | 16.5 | **19.18** | **303 mm²** | **15.174 N** |

v1'de omuz zaten denenmiş ve kaldırılmıştı — çünkü R_pitch 15.5'te omuza
yer kalmıyor, boncuklar omuza çarpıyordu. **R_pitch 12.0'a inince** omuz
303 mm² oluyor: eski durdurmanın **3.2 katı kuvvet**.

Anti-çakışma sınırı R_pitch ≥ 11.89 (komşu yuvaların boncukları değmesin);
12.0 bu sınırın hemen üstünde, arka boncuk ekseni 9.11 mm.

### Enerji dengesi
- TPU halka (2 mm, 303 mm²): 1.2 mm ezilir → **7.3 J**
- Kalan 5.5 J elastik, 15.174 N'de **0.36 mm**
- Tepe kuvvet ≤ 15.174 N, PETG sınırının altında ✓

## 4. YOLDA YAKALANAN HATA

Koni, TPU kalınlığı kadar **geriden** başlıyor; bu kayma boncuk açıklığını
yiyor. İlk denemede namlu ağzında boncuklar koniye **1.1 mm giriyordu**.
Düzeltme: omuz yarıçapına `t_omuz × tan(ALFA)` kadar fazladan pay eklendi
ve bu artık ALFA'dan türetiliyor (açı değişirse kendiliğinden düzeliyor).

Doğrulama (`cad/kontrol_omuz.py`):
- omuz düzleminde pay **+2.68 mm**
- namlu ağzında pay **+1.00 mm**

## 5. PERFORMANSA ETKİSİ: YOK

| Gmod | v1 mesafe | **v1.1 mesafe** | v1.1 pay |
|---|---|---|---|
| 0.25 MPa | 0.50–0.84 m | 0.49–0.83 m | 1.07× |
| 0.45 MPa | 0.80–0.98 m | **0.79–0.97 m** | 1.14× |
| 0.65 MPa | 0.87–1.06 m | 0.86–1.05 m | 1.17× |

Fark 1–2 cm. Yani daha iyi durdurma **bedava geldi.**

## 6. BASKIDA NE DEĞİŞTİ

| Dosya | Durum |
|---|---|
| `01a_namlu_govde` | değişmedi |
| `01b_agiz_basligi` | **YENİ** — durdurma omuzu eklendi (31.8 → 40.6 cm³) |
| `02_kapsul` | **YENİ** — yuvalar R12.0'a çekildi |
| `10_omuz_halkasi` | **YENİ PARÇA** — TPU 95A, Ø43 × 2 mm halka, 0.7 g |
| diğerleri | değişmedi |

TPU halka omuzun arkasındaki cebe **yapıştırılır** (yk..yk+2 mm).
Yerinden çıkarsa PETG omuz yedek olarak devrede kalır — ama tam gerdirilmiş
atışta yapıştırıcı şart.

## 7. TEST MERDİVENİ (yine de kademeli git)

Omuz 15.174 N taşıyor ve tam atış 12.8 J gerektiriyor; hesap tutuyor ama
**hiç gerçek veri yok**. İlk atışı yine düşük çekişle yap:

| çekiş | 1 bant | 2 bant |
|---|---|---|
| 40 mm | 1.6 J | 3.1 J |
| 55 mm | 2.7 J | 5.4 J |
| 70 mm | 4.2 J | 8.3 J |
| 91 mm (tam) | 6.6 J | **12.8 J** |

Her atıştan sonra omuz halkasına ve kapsülün ön kenarına bak.

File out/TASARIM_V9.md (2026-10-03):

# TASARIM v9 — ELDEKİ MALZEMELERLE NİHAİ REVİZYON

> **GÜNCEL DEĞİL — bkz. `out/TEST_1.md`.** Bu doküman 12 boncuk / 30° / 4 bant
> konfigürasyonunu anlatır. Test konfigürasyonu 6 boncuk / 40° / 2 bant olarak
> değişti.

Ölçülen boncuk: **Captain 1216, Ø9 mm, 4 g, ortası delikli.**
Ø9 kurşun + Ø2 mm delik = **4.01 g** → ölçümle tutarlı.
(Önceki Ø8 varsayımı 14921 kg/m³ sahte yoğunluk veriyordu; o ölçüm hatalıydı.)

---

## 1. NİHAİ TASARIM

### Ağ
| | |
|---|---|
| Biçim | altıgen, köşeden köşeye **Ø2.2 m** (köşe yarıçapı 1.1 m) |
| Göz | **kare 220 mm** |
| İp | Hyper Dyneema **Ø0.60 mm / 45.40 kg** — göz, çevre halatı ve radyal bağların **hepsi aynı ip** |
| Bağ sayısı | 65 kesişim + 30 çevre + **40 radyal** = 135 |
| Ağdaki ip | 39.2 m · **kesilecek: 47.2 m** (elde 90 m → 1 deneme payı daha var) |
| Ağ kütlesi | 9.6 g |

**Yakalama kriteri — sayısal doğrulama.** Ağ düzlemindeki *en büyük boş daire* hesaplandı
(601×601 ızgara, her noktanın en yakın ipe uzaklığı):

| bölge | en büyük boş daire |
|---|---|
| iç kafes (r < 850 mm) | **220 mm** (göz hücresinin kendisi) |
| dış halka (r ≥ 850 mm) | **198 mm** |
| **tüm ağ** | **220 mm** |

9" pervane (229 mm) hiçbir yerden süzülemez. **Pay yalnızca 9 mm** — Talon'a 8" (203 mm)
pervane takılırsa bu kriter **çöker**, göz küçültülmelidir.

Kafes ±880 mm'de biter, çevre halatı 1100 mm'dedir; aradaki 220 mm'lik halkayı **40 radyal bağ**
doldurur (halat düğümleri arası tam 220 mm; radyal bağ boyu 102–381 mm, ort. 200 mm).
Dış halkanın iç kafesten *daha sıkı* çıkması, halkanın zayıf nokta olmadığını gösterir.
Ölçülü çizim: `out/AG_ORME_KILAVUZU.png`.

### Boncuklar
6 yuva × **2 × Ø9 mm (8 g/köşe)** = **12 boncuk, 48 g**.
İp boncukların deliğinden geçer, dışta figure-8 durdurma düğümü.

### Kapsül (yeniden boyutlandırıldı)
| | |
|---|---|
| Boy | 45 mm · 31.9 cm³ · ~**38.5 g** PETG |
| Yuva | 6 ad, Ø9.6 mm, derinlik 9 mm, **eğim 30°**, bölüm dairesi R16 mm |
| Hazne | Ø37.1 × 20 mm (ağ + arka boncuklar) |

### Namlu — İKİ PARÇA
| | |
|---|---|
| Boy | 149.8 mm · iç Ø43.4 mm (**değişmedi**) |
| Iraksak koni | **30°**, y=141 mm'den ağza — tamamen **ağız başlığı** parçasının içinde |
| Bölme | y=128 mm, spigot 14 mm, boşluk 0.25 mm, 3 × M3 radyal vida |
| Hacim | gövde 122.60 + başlık 31.82 = 154.42 cm³ (tek parça 155.01 → çakışma yok) |

> Koni açısı değiştiği için **sadece ağız başlığı** yeniden basılır; gövde parçası aynen geçerlidir.

### Bant
Zıpkın lastiği **Ø13 / iç Ø4**, **4 kol**, serbest boy 30.3 mm, H 14 mm, strok 91 mm.

### Kütle bütçesi
ağ 9.6 g + boncuk 48 g = **uçan 57.6 g**; + kapsül 38.5 g = **ivmelenen 96.1 g**.

---

## 2. MENZİL — BANT SERTLİĞİNİN FONKSİYONU OLARAK

Gerekli açılma yarıçapı = yarı kanat açıklığı = **0.859 m** (Talon 1718 mm).

| Gmod | Kurma kuvveti | v_çıkış | R_tepe | pay | **ATIŞ PENCERESİ** | genişlik |
|---|---|---|---|---|---|---|
| 0.25 MPa | 473 N | 20.6 m/s | 0.969 m | 1.13× | **1.34 – 1.48 m** | 0.14 m |
| 0.35 MPa | 662 N | 24.4 m/s | 0.996 m | 1.16× | **1.36 – 1.72 m** | 0.35 m |
| **0.45 MPa** | **852 N** | **27.7 m/s** | **1.013 m** | **1.18×** | **1.36 – 1.88 m** | **0.52 m** |
| 0.55 MPa | 1041 N | 30.7 m/s | 1.024 m | 1.19× | **1.36 – 2.01 m** | 0.65 m |
| 0.65 MPa | 1230 N | 33.3 m/s | 1.033 m | 1.20× | **1.37 – 2.11 m** | 0.74 m |

**Cevap: menzil ≈ 1.4 – 2.1 m.** Tüm makul sertlik aralığında ağ yeterince açılıyor
(pay ≥ 1.13×), ama pencere dar. Tipik lateks (0.45 MPa) varsayımıyla
**Talon 1.4–1.9 m öndeyken ateşlenmeli.**

### Neden bu kadar kısa
0.60 mm ip, tasarımın 0.165 mm ipine göre **metre başına 13.2× ağır ve 3.6× daha sürüklemeli**.
Orijinal tasarımın 4.0–4.5 m atış mesafesi bu iple **ulaşılamaz**; bu bir ayar değil,
malzemenin dayattığı sınırdır. Boncuk kütlesini artırmak da çözmüyor (24 g'a kadar tarandı).

### Açılma zaman geçmişi (0.45 MPa)
88 ms'de R = 1.01 m (tepe) → 240 ms'de R ≈ 0.25 m'ye **geri kapanır** → sonra serbest düşerken
yeniden yayılır (z negatif, işe yaramaz). **Kullanılabilir açık kalma süresi ~50 ms.**
Tetik zamanlaması bu yüzden ±9 ms hassasiyet ister.

---

## 3. BANT SERTLİĞİ HÂLÂ ÖLÇÜLMEDİ — NASIL ÖLÇÜLÜR

Ø13 bant için kesit A₀ = π/4·(13² − 4²) = **120.2 mm²**.

1. Banttan **tek kol** 50 mm kes, iki ucunu işaretle.
2. Bir ucu sabitle, kantarla çekerek **135 mm**'ye uzat (λ = 2.70).
3. Kantar okumasını N'ye çevir (kg × 9.81).
4. **Gmod [MPa] = F [N] / 308**

Örnek: 9.7 kg (95 N) → Gmod = 0.31 MPa.
Ölçtükten sonra yukarıdaki tablodan ilgili satırı oku.

---

## 4. AÇIK SORUNLAR (dürüst liste)

1. **Kurma kuvveti 473–1230 N.** Elle kurulamaz; kaldıraç veya vinç şart.
   *(Eski tasarım da ~1200 N istiyordu, bunu daha önce hiç raporlamamıştım.)*
2. **Pim yatak basıncı kritik.** 852 N'de Ø5 pim / 4 mm PETG duvarda 43 MPa →
   PETG ~50 MPa, **SF 1.16**. Pim yuvasına **çelik burç** veya daha kalın duvar gerekli.
   Pimin kendisi sorun değil (Ø5 çelik çift kesme SF 11×).
3. **Pencere 0.52 m / ~50 ms.** Tetik zamanlaması ±9 ms.
4. **Hiçbir yer testi yapılmadı**: ağ açılma/dolaşma, pervane kesme, düğüm verimi çekme testi.
5. **3 boncuk/yuva daha iyiydi ama sığmıyor.** Arkaya doğru yuvalar eksene yaklaştığı için
   komşu boncuklar çakışıyor; 3 boncuk Ø48 mm (25°) veya Ø51 mm (30°) namlu ister.
   Ø2.2/220/25°/3 boncuk → pencere 1.73–2.36 m (0.63 m). Namlu çapını büyütmeye değer mi,
   karar verilmedi.

---

## 5. BU REVİZYONDA DÜZELTİLEN HATALAR

- **Tepe tespiti yanlıştı.** `argmax(R[:yarı])` ağın serbest düşerken yeniden yayılmasını
  yakalıyordu; R_tepe 1.097 m ve 0.52–1.84 m penceresi **geçersizdi**. Artık **ilk yerel tepe**
  kullanılıyor; gerçek pencereler 0.3–0.7 m (benim raporladığım 1.0–1.7 m değil).
- **3 boncuk tek hatta çakışıyordu.** CAD 4.93 cm³ veriyordu, 6.37 olmalıydı. Geometrik sınır
  türetildi (R_arka ≥ 9 mm) ve 2 boncuğa inildi.
- **`malzeme_listesi.py`, `cad/ciz_v4.py`, `cad/ciz_montaj_rehber.py` çalışmıyordu** —
  yol refaktörü (`3d2888d`) `vyol()` çağrısı eklemiş ama import'u koymamıştı.
- **Malzeme listesi eski ağı sabit kodluyordu** (R 1.4, göz 140). Artık konfigden okuyor.
- **B7 satırı yanlış bölüme düşüyordu** (ikinci bir "B." başlığı açıyordu).
- **Örme kılavuzundaki radyal bağlar hiç çizilmemişti** — simülasyon onları modelliyordu ama
  kılavuz 220 mm'lik bağsız halkayı göstermiyordu. 40 bağ eklendi.
- **Bant ölçüm katsayısı eskiydi**: 473 değeri Ø15.2 bant içindi, Ø13 için **308**.

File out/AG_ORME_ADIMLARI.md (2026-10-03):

# AĞ ÖRME — ADIM ADIM

**Görsel: `out/AG_ORME_KILAVUZU.png`** (yanında aç, ölçüler orada)

```
ağ        : altıgen dış hat, köşeden köşeye Ø1800 mm, her kenar 900 mm
göz       : KARE, 220 mm
ip        : eldeki Dyneema Ø0.60 mm — hepsi aynı ip
toplam    : 25.8 m  (elinde 90 m → 64 m artar)
bağ       : 65 adet (41 kesişim + 24 çevre)
süre      : ~1.1 saat
bilye     : 12 × Ø8 (4 g) → köşe başına 2 adet
```

---

## 0 · ŞABLON — bunu atlama, elde düzgün olmaz

1. Yere **2 × 2 m** düz zemin (kontrplak, OSB ya da temiz beton).
2. Merkezi işaretle. **900 mm**'lik bir ipin ucuna kalem bağla, daire çiz.
3. Daire üzerinde pergeli **900 mm**'ye açıp 6 işaret at → altıgenin köşeleri.
   (Düzgün altıgende kenar = yarıçap, bu yüzden tutar.)
4. Köşeleri birleştir → altıgen dış hat.
5. İçine **220 mm aralıklı kare ızgara** çiz, iki yönde.
   Merkez çizgi x=0 ve y=0'dan başla, ±220, ±440, ±660 diye git.
6. Her ızgara çizgisinin **altıgen kenarı kestiği** noktaya çivi/raptiye çak.

---

## 1 · İPLERİ SER — kesme, sadece ger

**14 hat var.** Kesim listesi görselde ①. Her ucta **80 mm bağlama payı**
bırak, yani listedeki boya +160 mm ekleyerek kes. Toplam **16.2 m**.

| yön | konum | boy |
|---|---|---|
| yatay | y = 0, ±220 | 1320 mm (3 hat) |
| yatay | y = ±440, ±660 | 880 mm (4 hat) |
| dikey | x = 0, ±220, ±440 | 1320 mm (5 hat) |
| dikey | x = ±660 | 440 mm (2 hat) |

Her hattı iki ucundaki çiviye bağla. **Gergin ama aşırı değil** — elle
çekince 1–2 mm esneyecek kadar.

> **Neden sürekli:** ip boyunca düğüm yoksa tam dayanımını korur.
> Kesip düğümlersen dayanım yarıya iner.

---

## 2 · KESİŞİMLERİ BAĞLA — 41 adet (görsel ②)

Her kare kesişimde iki ip üst üste geçer. **Birbirine düğümleme** —
sadece kaymayı önle:

1. Ayrı bir **150 mm**'lik ince bağ ipi al (aynı Dyneema'dan ya da
   normal dikiş ipliğinden).
2. Kesişimin üstüne **çapraz sar**: önce bir yöne 3 tur, sonra dik yöne
   3 tur.
3. **İki yarım düğüm** (square knot), 2 mm bırakıp kes.
4. Üstüne **bir damla japon yapıştırıcı** — sargıyı kilitler.

> Kesişimler **bağdır, ek değildir**. İki mesh ipini birbirine sheet bend
> ile bağlarsan ipler kesilmiş olur ve dayanım düşer.

---

## 3 · ÇEVRE HALATINI EKLE — 24 bağ (görsel ③)

1. Altıgenin 6 kenarı boyunca aynı ipi ser — kenar başına **900 mm**,
   toplam **5.4 m**. Uçları bir köşede birleştir (double fisherman's).
2. Her mesh ipinin kenara ulaştığı yerde, ipi halatın etrafına
   **3–4 TUR SAR** (lacing), sonra kendi üstüne iki yarım düğüm.
   **DÜĞÜMLE BAĞLAMA.**

> Düğümlü uç 245 N, sarılmış uç ~400 N taşır. Ölçülen tepe yük ~17 N —
> yani ikisi de yeter, ama sarmak bedava pay.

> Mesh kenarı ile altıgen kenarı arasındaki mesafe yere göre 0–220 mm
> değişir (kare ızgara altıgene tam oturmaz). Bu normaldir; bağ ipini
> gereken boyda kes.

---

## 4 · BİLYELERİ BAĞLA — 6 köşe, 12 bilye (görsel ④)

1. Her köşe için **70 mm** ip kes.
2. İpi **iki bilyenin deliğinden** geçir (köşe başına 2 × Ø8 = 8 g).
3. Dışta **figure-8 durdurma düğümü** — bilyeler düşmesin.
4. Diğer ucunu halatın **köşesine** sar + bağla.
5. Bilye ile köşe arası serbest boy: **40 mm**.

---

## 5 · KONTROL

- [ ] Köşeden köşeye **1800 ± 20 mm**
- [ ] Altıgenin her kenarı **900 ± 10 mm**
- [ ] 6 köşede 2'şer bilye, hepsi sağlam
- [ ] Çevre halatı kesintisiz, hiçbir yerde gevşek değil
- [ ] Hiçbir kesişim kaymıyor (elle it, kıpırdamamalı)
- [ ] **Tart: ağ + bilye ≈ 55 g** (ağ 7.1 g + bilye 48 g)

---

## 6 · KATLAMA — dolanmanın asıl belirleyicisi

1. Ağı yere tam açık ser, bilyeleri 6 köşeye yay.
2. Üzerine **ince talk pudrası** serp, elle dağıt.
3. **Merkezden başlayarak** akordeon gibi katla; her kat **35 mm**
   genişliğinde olsun.
4. Katlanmış şeridi **merkez uçta, bilyeler dışta** kalacak şekilde rulo yap.
5. Hazneye **merkez önce** koy → açılırken dış halka önce çıkar.
6. Bilyeleri yuvalarına otur, ağzına pelur kâğıdı noktasal yapıştır.

> **İlk seferde 3 kez tekrarla.** Katlayıp çıkar, nasıl açıldığına bak.
> Model bu kısmı hesaplayamıyor — tek doğrulama senin gözün.

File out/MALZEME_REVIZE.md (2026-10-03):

# ELDEKİ MALZEMELERLE REVİZE — ölçüm sonuçları

## Aldığın malzemeler vs tasarım

| | tasarım | eldeki | oran |
|---|---|---|---|
| iplik çapı | 0.165 mm | **0.60 mm** | 3.6× |
| iplik kesiti | 0.021 mm² | 0.283 mm² | **13.2×** |
| iplik kütle/m | 0.021 g | 0.27 g | **13.2×** |
| iplik kopma | 64 N | **445 N** | 6.9× |
| bilye | Ø12.7 / 12.16 g | Ø8 / **4 g** | **0.33×** |
| bant dış çap | 15.2 mm | **13 mm** | 0.86× |

> ⚠️ Ø8 kürenin 4 g olması **14921 kg/m³** yoğunluk demek — kurşundan ağır,
> tungstenden hafif. Ya çap ya kütle yaklaşık ölçülmüş olmalı.
> **Hassas tartıp söyle**; balistikte belirleyici olan kütledir.

## Bulgu 1 — ilk denemede ağ HİÇ AÇILMIYOR

| R_ag | göz | ağ | R_tepe | durum |
|---|---|---|---|---|
| 1.30 | 200 | 14.18 g | 0.568 | YETERSİZ |
| 1.20 | 200 | 12.24 g | 0.622 | YETERSİZ |
| 1.00 | 200 | 8.77 g | 0.566 | YETERSİZ |

Gereken 0.859 m. Sebep: bilyeler 3× hafifledi, ağ 13× ağırlaştı →
açma momentumu **46× yetersiz**.

## Bulgu 2 — koni açısı açılmayı kurtarıyor

| α | R_tepe |
|---|---|
| 13° *(tasarım)* | 0.566 |
| 25° | 0.792 |
| **35°** | **0.908** ✅ |
| 45° | 0.980 ✅ |

## Bulgu 3 — AMA 0.60 mm iplik menzili ÖLDÜRÜYOR

Koni açısı açılma sorununu çözüyor, **menzil sorununu çözmüyor**:

| bilye kütlesi | 6 bilye | PENCERE |
|---|---|---|
| 4 g | 24 g | 1.14 – 1.44 m |
| 8 g | 48 g | 1.06 – 1.60 m |
| 12 g | 72 g | 1.04 – 1.70 m |
| **24 g** | **144 g** | **1.02 – 1.80 m** |

**Bilye ne kadar ağırlaşırsa ağırlaşsın pencere 1.8 m'yi geçmiyor.**
0.60 mm iplik, çapıyla orantılı sürükleme yaratıyor (3.6×) ve ağı
frenliyor. Gözü açmak da kurtarmıyor (göz 350 mm'de bile 1.58 m) —
üstelik göz > 230 mm olunca pervane garantisi kalkıyor.

## Bulgu 4 — ÇÖZÜM: karma kullanım

**0.60 mm ipi ÇEVRE HALATI olarak kullan** (7–8 m, orada dayanım lazım
ve uzunluk kısa), **meshi ince iple ör**:

| mesh ipi | bilye | α | R_tepe | PENCERE |
|---|---|---|---|---|
| 0.165 mm | 4 g ×1 | 15° | 0.923 | 3.16 – 4.06 |
| 0.165 mm | **4 g ×2 = 8 g** | **20°** | **1.106** | **2.20 – 5.78** ✅ |
| 0.165 mm | 4 g ×3 = 12 g | 25° | 1.277 | 1.64 – 6.08 |

**Önerilen: yuva başına 2 bilye (toplam 12 adet), α = 20°.**
Pencere 2.20 – 5.78 m — eski tasarımın 3.56 – 6.54'üne yakın, hem de
eldeki bilyelerle.

## KARAR

```
mesh ipi   : 0.165 mm Dyneema örgü  -> SATIN ALINACAK (~130 TL / 100 m)
çevre ipi  : eldeki 0.60 mm          -> 8 m kullan, 82 m artar
bilye      : eldeki Ø8 / 4 g         -> YUVA BAŞINA 2 ADET, 12 adet
koni açısı : 13° -> 20°              -> kapsül yuvaları değişecek
ağ         : Ø2.2 m (R_ag 1.1), kare göz 200 mm
bant       : eldeki Ø13              -> sertlik ÖLÇÜLECEK
PENCERE    : 2.20 – 5.78 m
```

## Bandın sertliğini ölç — tasarım buna bağlı

Eldeki Ø13 lastiğin sertliği bilinmiyor. **50 mm kes, 135 mm'ye ger,
bagaj kantarıyla oku.**

```
Gmod [MPa] = okunan_kuvvet [N] / 473
```

| okursan | Gmod | 4 bant toplam | kurma/bant |
|---|---|---|---|
| 100 N (10 kg) | 0.21 MPa | 568 N | 14.5 kg |
| 200 N (20 kg) | 0.42 MPa | 852 N | 21.7 kg |
| 300 N (31 kg) | 0.63 MPa | 1136 N | 28.9 kg |

Sonucu söyle, çıkış hızını ve pencereyi ona göre yeniden hesaplayayım.

## Hâlâ açık
* Ø8 bilyenin gerçek kütlesi (hassas tartım)
* Ø13 bandın Gmod'u (çekme testi)
* 12 bilye için kapsül yuvaları yeniden çizilecek (2 bilye derinliği)

---

# EK — "SADECE ELDEKİ İPİ KULLAN" KARARI

Kullanıcı: *ince ip almayalım, elimizdeki tek ip bu. Ağı küçültelim,
gözü açalım, iplik yoğunluğunu azaltalım.*

Yapıldı. 0.60 mm iple **ağ çapı ve göz aralığı** tarandı (bilye 2×4 g,
koni açısı da birlikte optimize edildi).

## Pervane garantisi korunarak (göz ≤ 220 mm < pervane Ø230)

| çap | göz | α | iplik | ağ | R_tepe | PENCERE | genişlik |
|---|---|---|---|---|---|---|---|
| Ø2.2 | 200 | 25° | 38.0 m | 10.43 g | 0.938 | 1.80 – 2.30 | 0.50 |
| Ø2.0 | 220 | 25° | 29.6 m | 8.12 g | 0.971 | 1.42 – 2.24 | 0.82 |
| **Ø1.8** | **220** | **25°** | **25.8 m** | **7.08 g** | **1.039** | **2.02 – 2.32** | **0.30** |
| Ø1.8 | 200 | 25° | 26.4 m | 7.25 g | 1.033 | 1.68 – 2.02 | 0.34 |
| Ø2.0 | 200 | 30° | 32.0 m | 8.77 g | 1.106 | 0.52 – 1.84 | 1.32 |

### Seçim: Ø1.8 m · göz 220 mm · α 25°
```
iplik      : 25.8 m   (elinde 90 m -> 64 m artar)
bağ        : 65 adet  (~1.1 saat el emeği)   [eskiden 142 bağ / 2.5 saat]
ağ kütlesi : 7.08 g
uçan kütle : 87 g   (ağ 7 + bilye 48 + kapsül 32)
v_eksenel  : 26.4 m/s
R_tepe     : 1.039 m   (gereken 0.859 — %21 pay)
PENCERE    : 2.02 – 2.32 m
```

## ⚠️ İKİ ÖDÜN — bilerek kabul ediliyor

**1. Menzil 5.78 → 2.32 m.**
0.60 mm ipin sürüklemesi aşılamıyor. Daha önce ölçülmüştü: bilyeyi 24 g'a
çıkarsan bile pencere 1.8 m'yi geçmiyordu. Ağı küçültüp seyreltmek
2.32 m'ye kadar çıkardı — **bu ipin fiziksel tavanı.**
İnce ip (0.165 mm) alınırsa 5.78 m'ye çıkar.

**2. Pervane payı %22 → %4.**
Göz 220 mm, pervane Ø230 mm. Pervane gözün tam ortasına denk gelirse
diske giren ip uzunluğu yalnızca ~67 mm (göz 200'de 143 mm idi).
Gazebo ölçümü ağın süpürülürken onlarca ip geçirdiğini göstermişti, ama
bu pay artık ince.

> **Göz 200 mm'de kalmak istersen:** pencere 1.68 – 2.02 m'ye düşer
> (0.30 m daha yakın) ama pervane payı %13 olur. Menzil mi güvence mi —
> senin kararın.

## Ne değişti, ne değişmedi

| | önce | şimdi |
|---|---|---|
| ağ çapı | Ø2.6 m | **Ø1.8 m** |
| göz | 200 mm | **220 mm** |
| iplik | 45 m (0.165 mm) | **25.8 m (0.60 mm)** |
| bağ / emek | 142 / 2.5 sa | **65 / 1.1 sa** |
| koni açısı | 13° | **25°** |
| bilye | 6 × 12.16 g | **12 × 4 g** (yuva başına 2) |
| pencere | 3.56 – 6.54 m | **2.02 – 2.32 m** |

**Kapsül yeniden çizilecek:** yuva açısı 13° → 25°, her yuva 2 × Ø8
bilye alacak derinlikte.

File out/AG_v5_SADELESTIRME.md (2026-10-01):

# AĞ SADELEŞTİRME (v5) — "tek ip yeter" tezinin sonuçları

## Tetikleyici
Kullanıcı itirazı: *"Bu ağın tek bir ipinin pervaneye değmesi uçağı
düşürmeye yeter. Sen ipi bu kadar fazla kullanıyorsun ama ağın hazne
içinde açılıp açılmayacağını, birbirine dolanıp kalmayacağını hiç
düşünmüyorsun."*

İtirazın **üç parçası doğru, bir parçası fazla iddialı** çıktı.

---

## 1. "Tek ip pervaneye değse yeter" — DOĞRU ✓
Motor stall torku ipi `T = τ/r_sarım` ile gerer:

| τ_stall | r_sarım 12 mm | 20 mm | 30 mm |
|---|---|---|---|
| 0.15 N·m | 12.5 N | 7.5 N | 5.0 N |
| 0.30 N·m | 25.0 N | 15.0 N | 10.0 N |
| 0.50 N·m | 41.7 N | 25.0 N | 16.7 N |

Tek ip: lif 64.1 N, düğümlü 35.3 N. **Dokuz durumun sekizinde tek ip yeter.**

### Bunun büyük sonucu: GÖZ ŞARTI DEĞİŞTİ
Eski kriter: *pervane diskinin içinde bir DÜĞÜM bulunmalı* → `göz < D/√2 = 163 mm`
Yeni kriter: *pervane diskini en az bir İP kesmeli* → `göz < D = 230 mm`

Pervane Ø230 mm. **Göz 180 mm seçildi (%22 pay).**
En kötü durumda (pervane hücre ortasında) diske giren ip uzunluğu 143 mm —
sarılmaya fazlasıyla yeter.

## 2. "Ağ aşırı büyük, bu kadar ipe gerek yok" — DOĞRU ✓
Kaba göz **her eksende** daha iyi çıktı (az iplik = az sürükleme = uzak menzil):

| tasarım | bağ | iplik | kütle | emek | R_açık | pencere |
|---|---|---|---|---|---|---|
| ESKİ: altıgen Ø2.8 göz140 | 811 | 100 m | 2.08 g | 13.5 sa | 1.170 | 3.56 – 6.44 |
| ara: kare Ø2.8 göz140 | 315 | 81 m | 1.69 g | 5.2 sa | 1.127 | 3.56 – 6.22 |
| **YENİ: kare Ø2.6 göz180** | **179** | **59 m** | **1.17 g** | **3.0 sa** | **1.129** | **3.58 – 6.62** |

**Bağ %78 ↓, iplik %41 ↓, el emeği %78 ↓ — ve pencere 0.18 m UZADI.**

## 3. "Dolanmayı hiç düşünmüyorsun" — HAKLI ELEŞTİRİ ✓
Modellememiştim. Ölçülebilen göstergeler:

| gösterge | eski (altıgen) | yeni (kare) |
|---|---|---|
| toplam iplik | 100 m | 59 m |
| bağ sayısı (takılma noktası) | 811 | 179 |
| **sürekli ip sayısı** | **1257 ayrı kenar (ort. 8 cm)** | **~28 ip (ort. 1.8 m)** |
| hazne dolgu oranı | %10.5 | %5.9 |

En önemlisi sonuncudan bir önceki: altıgen kafeste her kenar ayrı bir
parçadır; kare gözde ipler baştan sona **süreklidir**. Paraşüt ip hattı
mantığı — az sayıda uzun ip, çok sayıda kısa parçadan çok daha düzgün açılır.

> **MODELLENEMİYOR:** ipin ipe takılması (self-contact). Rijit-cisim + LCP
> çözücüsüyle çözülemez; ip/kumaş çözücüsü gerekir. **Tek doğrulama yolu
> YER TESTİ:** ağı pakete koy, yerde ateşle, yüksek hızlı kamera ya da
> gözle açılmayı doğrula. Bu test YAPILMADAN uçuş denemesine geçilmemeli.

## 4. "Bilyeler uçağı kırar" — FAZLA İDDİALI ✗
| bağıl hız | tek bilye | 6 bilye |
|---|---|---|
| 15 m/s | 1.37 J | 8.2 J |
| 20 m/s | 2.43 J | 14.6 J |

20 m/s'de tek bilye 2.43 J — 0.8 kg'ı 30 cm'den düşürmeye denk. EPO köpüğe
çukur açar, kumanda yüzeyini sıkıştırabilir; **yapı kırmaz**. Gazebo ölçümü
de bunu doğruluyor: uçağa aktarılan 1.05 kg·m/s → 1.8 kg'lık uçakta
0.58–0.95 m/s hız değişimi. İtiyor, parçalamıyor.
**Asıl öldürücü mekanizma PERVANE; bilyeler ikincil.**

---

## 5. Gazebo doğrulaması (tetikleme 4.50 m — en ağır yük)
| tasarım | T_tepe | kopan | >%50 | pay | ağın hedefte | hedef v |
|---|---|---|---|---|---|---|
| kare Ø2.8 göz140 (4.65 m) | 7.8 N | 0 | 0 | 4.5× | %33 | 0.50 m/s |
| kare Ø2.6 göz200 | 16.9 N | 0 | 0 | 2.1× | %47 | 0.86 m/s |
| **kare Ø2.6 göz180** | **14.8 N** | **0** | **0** | **2.4×** | **%51** | **0.95 m/s** |
| kare Ø2.6 göz160 | 19.3 N | 0 | **2** | 1.8× | %55 | 0.87 m/s |

İki bulgu:
1. **Kaba ağ hedefe DAHA ÇOK seriliyor ve 1.9× fazla momentum aktarıyor.**
   Az sayıda uzun ip daha iyi sarıyor; ince örgü bir "yaprak" gibi kayıyor.
2. Gerilme arttı (yükü paylaşan eleman azaldı) ama 160/180/200 arasındaki
   fark (16.9 / 14.8 / 19.3 N) **temas saçılmasının içinde** — tek düze
   değil. Göz seçimi gerilmeye değil, pay + emek dengesine dayandırıldı.

## 6. Payı geri kazanmanın ucuz yolu: BAĞLANTI ŞEKLİ
Ölçülen tepe yük 14.8 N. Kapasite, mesh ipinin çevre halatına nasıl
bağlandığına bağlı:
* **düğümle** → 35.3 N → pay **2.4×**
* **sararak (lacing)** → ~64 N → pay **4.3×**

Düğüm atmadan, halatın etrafına sararak bağla. Bedava pay.

## 7. Kopmanın sonucu — kare gözün tek zayıf yanı
İpler sürekli olduğu için bir ip koparsa **2 m boyunca** hat gider ve yerel
açıklık `2×göz = 360 mm` olur; pervane (Ø230) o delikten geçebilir.
Altıgen kafeste tek kenar (8 cm) kaybı bu kadar önemli değildi.
Bu yüzden (6)'daki lacing şartı **tavsiye değil, gereklilik**.

---

## 8. Kesinleşen v5 ağ tanımı
```
dış hat      : altıgen, köşe yarıçapı 1.30 m (Ø2.60 m)
göz          : KARE 180 mm
mesh ipi     : Dyneema SK78 ÖRGÜ Ø0.165 mm, ~50 m, ~28 sürekli ip
çevre halatı : PE örgü Ø0.285 mm, 7.8 m (altıgenin 6 kenarı)
bağ          : ~179 (120 göz kesişimi + 59 çevre bağlantısı), ~3 saat
bilye        : Ø12.7 kurşun × 6, halatın 6 köşesinde
kütle        : 1.17 g ağ + 73 g bilye
açılma       : R = 1.129 m (gereken 0.859 m, %31 pay)
pencere      : 3.58 – 6.62 m
hazne dolgusu: %5.9
```

## 9. Sıradaki iş
1. **YER TESTİ** — dolanma/açılma. Modelin cevaplayamadığı tek şey.
2. Mesh ipi–halat bağlantısında lacing'i doğrula (çekme testi).
3. Pervane kenarında kesme testi (bkz. `IP_CAPI_KARAR.md` §1c).

---

## 10. GÜNCELLEME — statik göz kriteri ÇOK KATI çıktı (Gazebo ölçümü)

Göz sınırını "pervane diskinin içinde en az bir ip bulunsun" diye *statik*
koymuştum: `göz < 230 mm`. Bu, ağın tek bir anlık görüntüsü için doğru ama
**gerçekte ağ uçağın üzerinden GERİYE SÜPÜRÜLÜYOR** (ölçüldü: ağ merkezi
5.4 m'den 4.78 m'ye geri geliyor). Süpürme sırasında diskten kaç farklı
iplik geçtiğini ölçtüm:

| R_ag | göz | bağ | iplik | T_tepe | pervane: anlık max / **toplam farklı** | hedefte | hedef v |
|---|---|---|---|---|---|---|---|
| 1.3 | 180 | 179 | 57 m | 15.8 N | 5 / **18** | %50 | 0.89 m/s |
| **1.3** | **200** | **142** | **52 m** | **15.3 N** | **12 / 32** | **%54** | **0.86 m/s** |
| 1.3 | 220 | 133 | 48 m | **12.8 N** | 23 / **92** | %51 | 0.80 m/s |
| 1.2 | 200 | 133 | 45 m | 14.7 N | 13 / **32** | %58 | **1.03 m/s** |

**Her göz boyutunda diskten onlarca iplik geçiyor.** "Pervane gözün ortasına
denk gelip hiç ip kesmeyebilir" endişesi gerçekleşmiyor.

Ayrıca kabalaştıkça **iyileşiyor**: göz 220'de hem en düşük tepe gerilme
(12.8 N) hem en çok pervane teması (92 iplik). Yumuşak ağ daha iyi sarıyor.

**Seçim: göz 200 mm.** 220 ölçümde daha iyi çıktı ama statik garanti payı
%4'e iniyor; 200 hem %13 statik pay bırakıyor hem ölçümde 32 iplik veriyor.

### Hazneye sığma — kapandı
CAD'den gerçek hazne: **R 18.55 × L 16 mm = 17.3 cm³** (önce 20.5 demiştim, yanlıştı).

| iplik | katı hacim | %20 yoğunlukta | hazne dolumu |
|---|---|---|---|
| 100 m (eski) | 2.14 cm³ | 10.7 cm³ | %62 |
| **45 m (yeni)** | **0.96 cm³** | **4.8 cm³** | **%33** |

Hazne kapasitesi %20 yoğunlukta **162 m**. Sıkışmaya yakın bile değiliz.
**Sorun hacim değil, DÜZENLİ KATLAMA.** Rastgele tıkılırsa hacim yetse bile
dolanır — bu montaj talimatının meselesi, tasarımın değil.

### Nişan toleransı — küçültmenin gizli maliyeti
Ağın tüm uçağı örtmesi için R_açık ≥ 0.859 m (Talon yarı açıklığı) gerekir.
Fazlası nişan hatası payıdır:

| R_ag | R_açık | tam uçak örtme payı | sadece pervane payı |
|---|---|---|---|
| 1.3 | 1.141 m | **0.28 m** | 1.03 m |
| 1.2 | 1.086 m | 0.23 m | 0.97 m |
| 1.1 | 1.039 m | 0.18 m | 0.92 m |

Ağı küçültmek doğrudan nişan payını yiyor. "Tek ip pervaneye yeter" tezi
kabul edilirse pay ~1 m'ye çıkar, ama o zaman da ağın pervaneyi bulması
nişana bağlı kalır. **R_ag 1.3'te kalındı** — asıl kazanç gözden geldi,
ağı küçültmeye gerek yok.

## 11. KESİNLEŞEN v5 ağ
```
dış hat      : altıgen, köşe yarıçapı 1.30 m (Ø2.60 m)
göz          : KARE 200 mm
mesh ipi     : Dyneema SK78 ÖRGÜ Ø0.165 mm, ~45 m, ~26 sürekli ip
çevre halatı : PE örgü Ø0.285 mm, 7.8 m
bağ          : ~142 (83 göz kesişimi + 59 çevre), ~2.5 saat
bilye        : Ø12.7 kurşun × 6, halatın 6 köşesinde
kütle        : 0.95 g ağ + 73 g bilye
açılma       : R = 1.141 m   |   pencere 3.58 – 6.80 m
hazne dolumu : %33 (kapasite 162 m)
pervane teması: 32 farklı iplik (ölçüm)
tepe gerilme : 15.3 N, kopan 0  (lacing ile pay 4.2x)
```

### ESKİ → YENİ
| | eski (altıgen Ø2.8 göz140) | **yeni (kare Ø2.6 göz200)** |
|---|---|---|
| bağ | 811 | **142**  (−%82) |
| iplik | 100 m | **45 m**  (−%55) |
| el emeği | 13.5 saat | **2.5 saat**  (−%81) |
| hazne dolumu | %62 | **%33** |
| pencere | 3.56 – 6.44 m | **3.58 – 6.80 m** |
| hedefe serilme | %33 | **%54** |
| aktarılan momentum | 0.50 m/s | **0.86 m/s** |

## 12. Yol boyunca yaptığım hatalar
1. Altıgen kafes kurup düğüm sayısını 709 sandım; `params.py` baştan KARE
   göz varsayıyordu, malzeme listesindeki 259 doğruydu.
2. Çevre halatını (F2, listede vardı) modellemedim; onsuz kare ağın köşeleri
   desteksiz kalıp açılamıyordu — yanlış sonuca götürdü.
3. Hazne hacmini Python'daki eski `D_hazne`'den aldım (20.5 cm³); CAD'deki
   gerçek değer 17.3 cm³.
4. `PERVANE` sabitini tanımlanmadan önce kullandım; SDF üretimi sessizce
   çöktü, Gazebo 4 koşuyu ESKİ dünya dosyasıyla yaptı ve dördü de aynı
   sayıyı verdi. Üretici hatası artık koşuyu durduruyor.

---

## 13. v5 TAM ATIŞ SİMÜLASYONU (Gazebo) — ve ÖNEMLİ bir düzeltme

Ağ: Ø2.6 m, kare göz 200 mm, 142 düğüm, 269 eleman. Hedef: Talon, seyir trimli.
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

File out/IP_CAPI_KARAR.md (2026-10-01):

# İPLİK İNCELTME — KARAR

**Soru:** İpi inceltip menzili uzatalım; pervanenin kesmesine dayanırsa.

**Cevap: İNCELTME. Ama sınırı koyan, beklediğimiz yer değil.**

---

## 1. "Pervane ipi keser mi?" — ÜÇ ayrı mekanizma, çapa bağımlılıkları FARKLI

### (a) Kanadın serbest uçan ipe çarpması — ÇAPTAN BAĞIMSIZ
Enine darbede ip bir örse (anvil) dayalı değildir; sadece hızlanıp savrulur.
Smith enine darbe teorisi: kritik hız yalnızca malzemeye bağlıdır.
```
c   = sqrt(E/rho) = 9632 m/s          (Dyneema SK78)
e_b = 3.33 %
V_c = 1022 m/s
```
Pervane ucu (Ø230 mm): 7000 rpm → 84 m/s, 11000 rpm → 133 m/s.
**8× pay. Bu mekanizma inceltmeyi sınırlamıyor.** (Balistik liflerde tek-lif
V50'sinin çaptan bağımsız olmasının sebebi budur.)
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

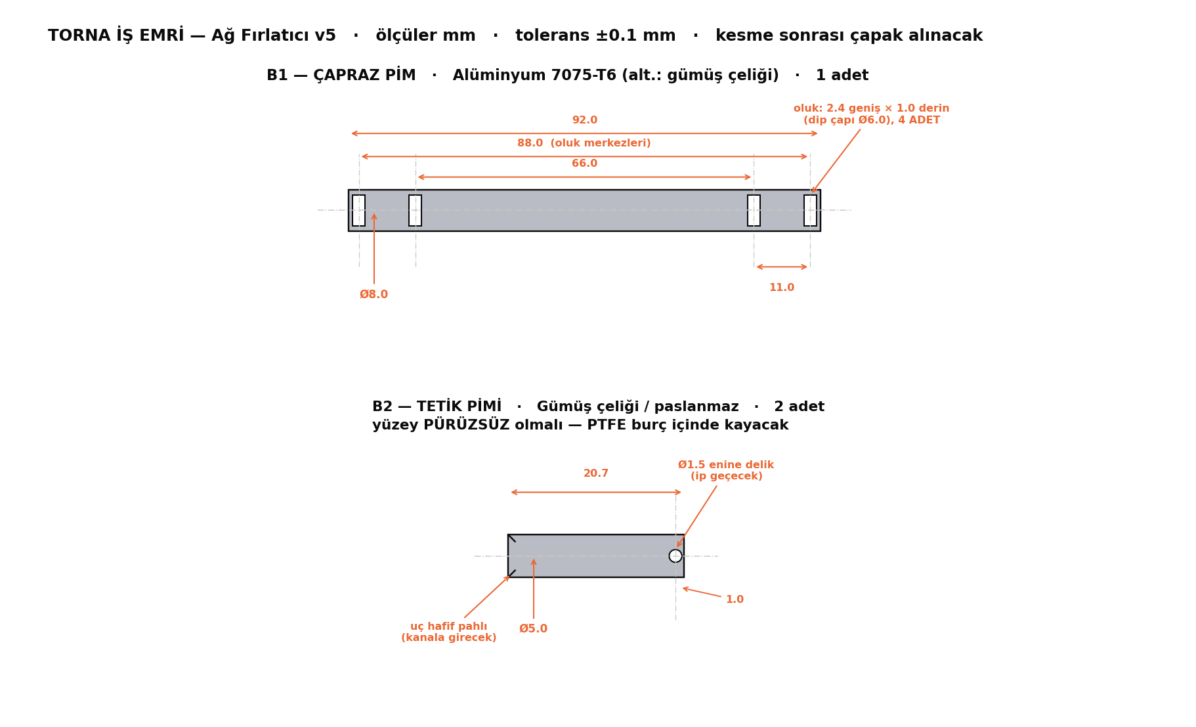
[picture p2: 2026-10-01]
TORNA_IS_EMRI.png

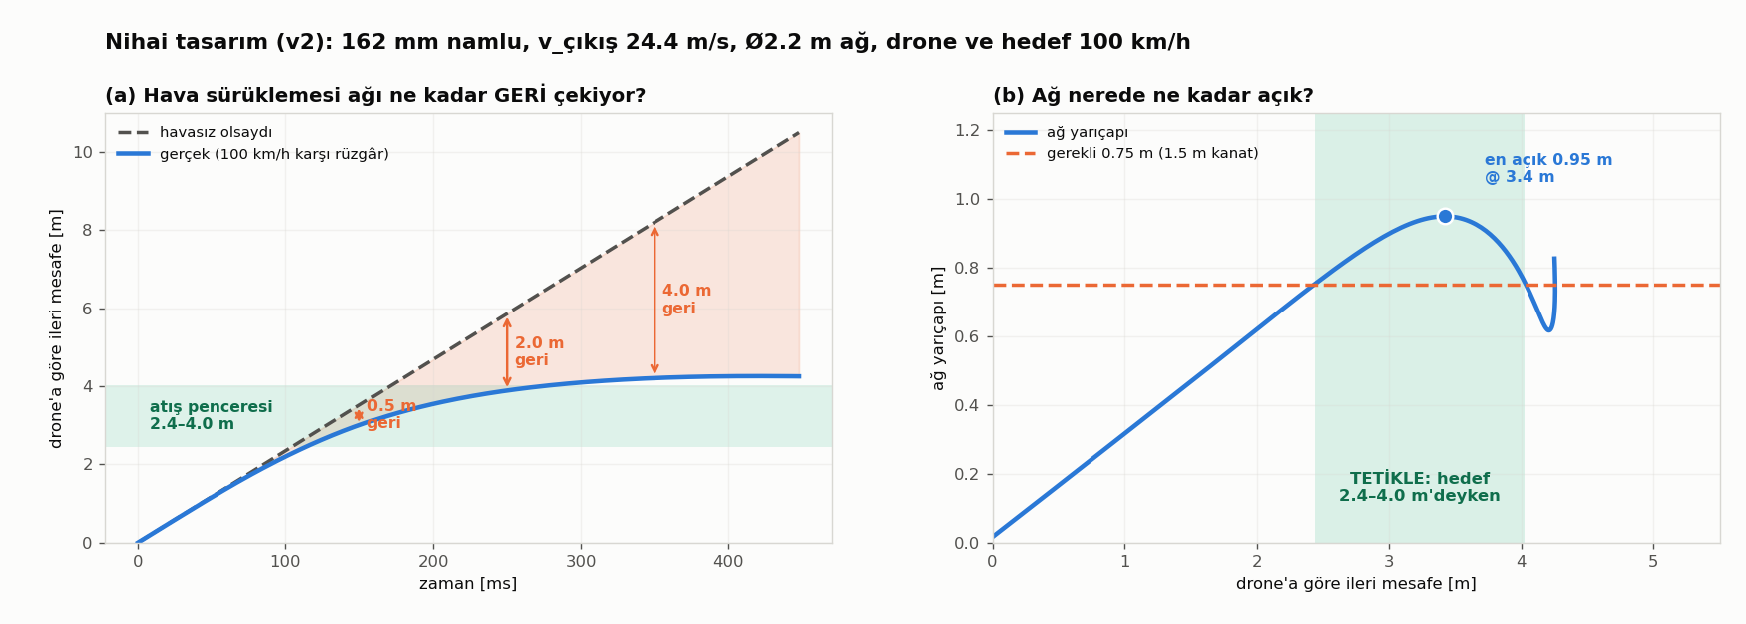
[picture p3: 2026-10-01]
out/surukleme_v2.png

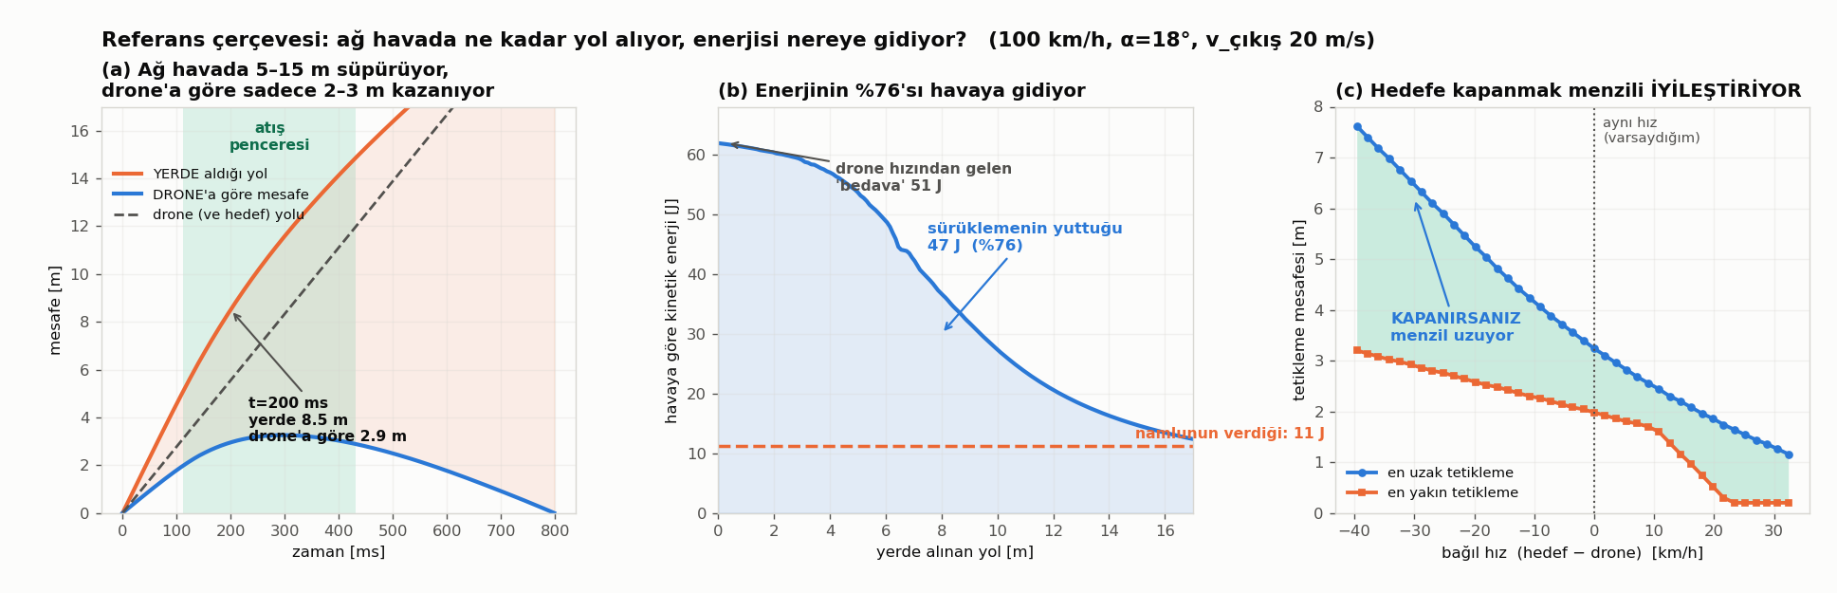
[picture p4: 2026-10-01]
out/cerceve.png

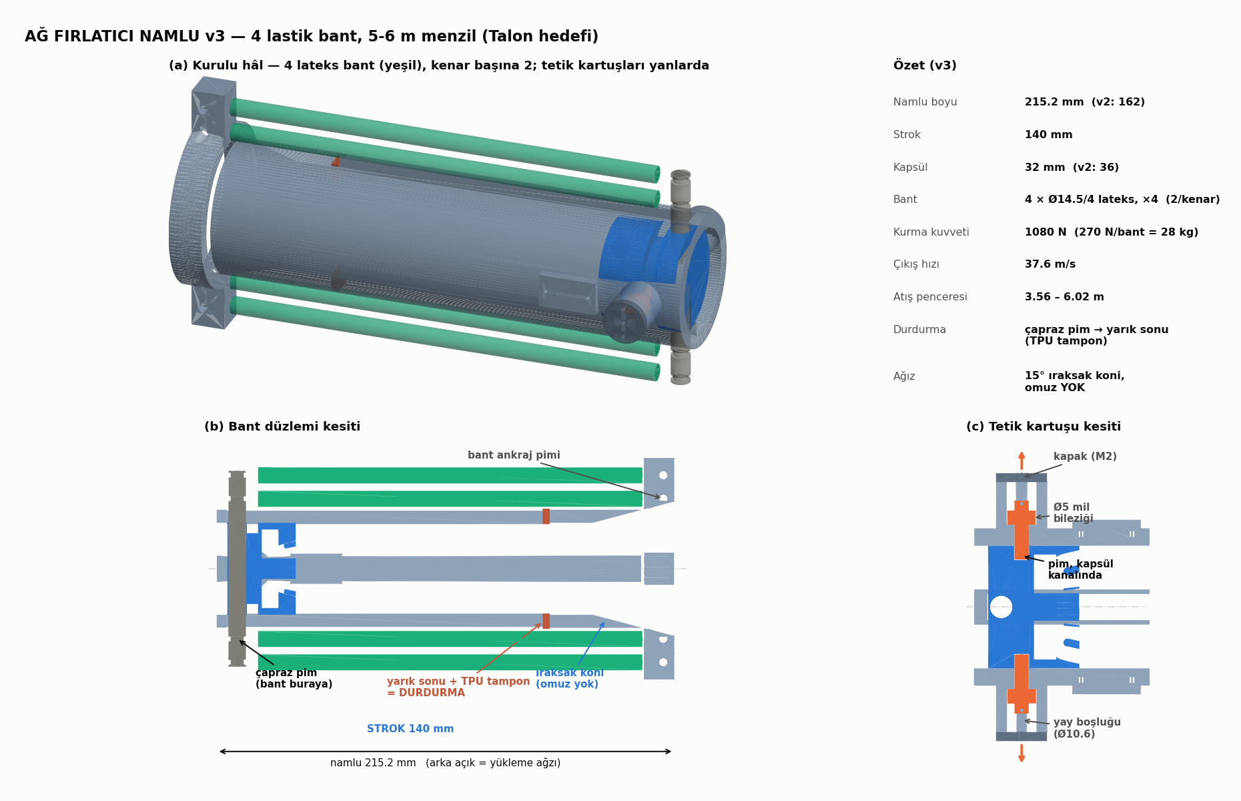
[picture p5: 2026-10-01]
out/cad_v3.png

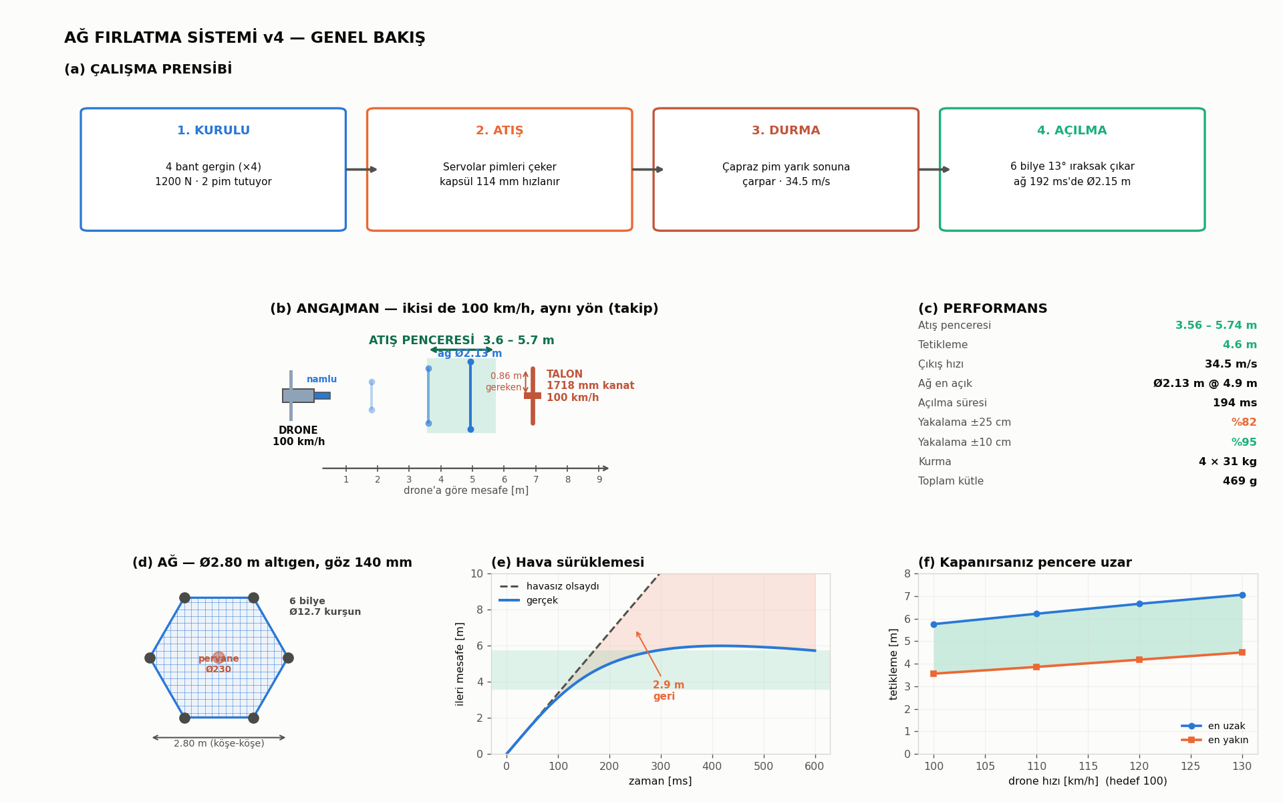
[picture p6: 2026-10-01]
out/REHBER_sistem.png

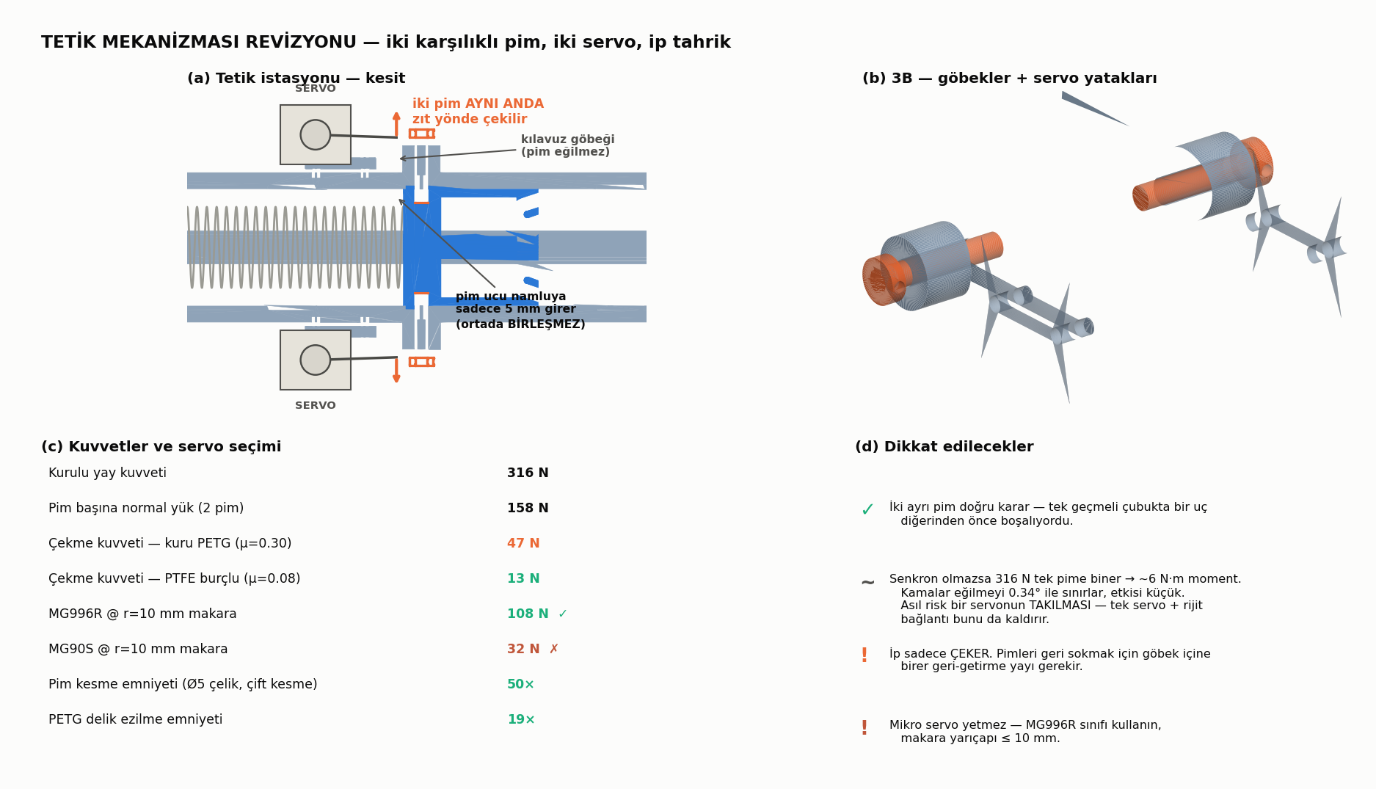
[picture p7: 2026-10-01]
out/cad_tetik.png

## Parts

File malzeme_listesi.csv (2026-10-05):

Grup | No | Parca | Adet | Malzeme / Ozellik | Olcu | Toplam kutle [g] | Not
A. 3D BASKI | A1 | Namlu govdesi (bilezik + bant kulaklari + 2 tetik gobegi + 2 servo yatagi dahil) | 1 | PETG (tercih ASA - UV'ye dayanikli) | O55.4 dis / O43.4 ic x 149.8 mm, 2 duz yarik 6.4 mm | 233.2 | Dik bas (eksen Z), 4 cevre + %50 gyroid. Yariklar ve delikler destek istemez.
A. 3D BASKI | A2 | Kapsul (arka blok + tutma kanali + ag haznesi + 6 bilye yuvasi) | 1 | PETG | O43.1 x 43 mm, hazne O37.1 x 16 mm, yuva acisi 40 derece | 109.7 | Agiz yukari bas. Arka blok 16 mm yuk tasir: 5 cevre + %60 dolgu.
A. 3D BASKI | A3 | Tetik kartus kapagi | 2 | PETG | O18 x 3 mm, ortada O2 ip deligi, 2x O2.2 vida deligi | 1.9 | %100 dolgu.
A. 3D BASKI | A4 | Servo ip makarasi | 2 | PETG | O8 mm (r=4 mm) tambur, servo dislisine oturur, O1.5 ip deligi | 0.8 | Servonun kendi kol vidasiyla sabitlenir.
A. 3D BASKI | A5 | Yarik sonu durdurma tamponu | 2 | TPU 95A | 6.2 x 3 x 7 mm | 0.5 | Yarik on ucuna CA ile yapistir. Kapsulun carpma yukunu yumusatir (~450 N).
A. 3D BASKI | A6 | Arka toz kapagi (opsiyonel) | 1 | PETG | O43 tapa, ortada O10 havalandirma | 2.0 | Arka agiz yukleme agzidir; ucusta toz/kir girmesin diye.
B. METAL / ISLEME PARCALAR | B1 | Capraz pim | 1 | Aluminyum 7075-T6 cubuk (alternatif: gumus celigi) | O8 x 124 mm; her ucta IKI oluk: r=46 ve r=57 mm, 2.4 mm genislik x 1 mm derinlik | 15.8 | 4 bant icin 4 oluk. Egilme SF 4.1 @ 1080 N. O6 YETERSIZ (SF 1.7).
B. METAL / ISLEME PARCALAR | B2 | Tetik pimi | 2 | Gumus celigi / paslanmaz cubuk | O5 x 20.7 mm, ust uctan 1 mm'de O1.5 enine ip deligi, uc hafif pahli | 6.6 | Uc kapsul kanalina girer; yuzey puruzsuz olmali.
B. METAL / ISLEME PARCALAR | B3 | Mil bilezigi (pim yakasi / yay tablasi) | 2 | Celik, set vidali (DIN 705) | O5 ic / O10 dis / 5 mm genislik, M3 set vida | 4.4 | Pim ucundan 12.2 mm'ye sabitlenir (dinlenmede uc kanal dibine 0.3 mm pay).
B. METAL / ISLEME PARCALAR | B4 | Geri getirme yayi (basma) | 2 | Yay celigi | ic O>=5.3, dis O<=10.2, tel ~0.5-0.6 mm, serbest boy ~13 mm, blok boy <=4 mm | 0.6 | Dinlenmede 10 mm (on yuk), cekilince 4 mm. Hazir yay setlerinden secilebilir.
B. METAL / ISLEME PARCALAR | B5 | Bant ankraj pimi | 2 | Paslanmaz celik pim | O4 x 16 mm | 3.2 | Agiz kulagindaki enine delige gecer, bant halkasini tutar. Uclara CA damlasi veya kucuk segman.
B. METAL / ISLEME PARCALAR | B6 | Ip yonlendirme pimi | 2 | Paslanmaz celik pim | O3 x 10 mm | 1.2 | Kapaktan radyal cikan ipi servo tamburuna cevirir. Puruzsuz olmali (veya O6 mini makara).
C. STANDART BAGLANTI ELEMANLARI | B7 | PTFE burc (tetik pimi) | 2 | PTFE/teflon burc | ic O5.0 / dis O7 x 10 mm | 0.6 | Namlu delige gecer. Surtunmeyi mu=0.18'den 0.08'e dusurur - servo secimi buna bagli.
C. STANDART BAGLANTI ELEMANLARI | C1 | M2 isil gomme insert (heat-set) | 8 | Pirinc | M2 x 3 mm | 1.2 | 4 adet kapak vidasi + 4 adet servo vidasi icin (PETG'ye havyayla).
C. STANDART BAGLANTI ELEMANLARI | C2 | M2 x 6 civata (kapak) | 4 | Paslanmaz, silindir basli | M2 x 6 | 0.8
C. STANDART BAGLANTI ELEMANLARI | C3 | M2 x 8 civata (servo) | 4 | Paslanmaz | M2 x 8 | 1.0 | Servonun kendi vidalari kisa kalirsa.
C. STANDART BAGLANTI ELEMANLARI | C4 | M3 set vida (mil bileziklerinin kendi vidasi) | 2 | Celik | M3 x 3 | 0.0 | Bilezikle gelir; diş sabitleyiciyle (Loctite 243).
D. TAHRIK — LATEKS BANT | D1 | Lateks tup (zipkin lastigi) | 2 | SAF DOGAL KAUCUK LATEKS (silikon/EPDM OLMAZ) | O14 dis / O4 ic (ELDEKI ZIPKIN LASTIGI); kesim boyu ~130 mm (calisma 30 mm + on 45 + arka 55 mm delme/katlama payi) | 32.8 | KENAR BASINA 1 ADET. Kurulu uzama x4. SERTLIK OLCULMEDI — tek kol 50->135 mm cekip Gmod[MPa]=F[N]/308. 0.45 MPa'da 213 N/bant (22 kg), toplam kurma 426 N.
D. TAHRIK — LATEKS BANT | D2 | Enine tutma pimi (BANTI DELER) | 2 | Celik mil / cubuk | O4.0 x 26 mm (ucu hafif sivri) | 5.2 | Bant O14 delikten gecer; pim kulagin BIR yan duvarindan girer, bandi deler, KARSI duvardaki delige oturur. Delik O4.2, on yuzden 6 mm geride. O3 de sigar ama sert bantta egilme emniyeti 1.0'a dusuyor — O4 kullan.
D. TAHRIK — LATEKS BANT | D3 | Arka kilit pimi (BANTI DELER) | 2 | Celik mil | O4.0 x 25 mm | 5.0 | Bant capraz pimin 14 mm oluguna sarilir, tail 30 mm geri katlanir; bu pim ana kolu ve tail'i BIRLIKTE deler. Capraz pimin ~15 mm arkasina.
E. TETIK TAHRIK — ELEKTRIK | E1 | Servo | 2 | MG996R sinifi (>=11 kg.cm @6V, metal disli) | 40 x 20 x 37 mm | 110.0 | Pim basina 213 N yuk -> PTFE burcla ~34 N cekme. Mikro servo YETMEZ. Iki servo AYNI sinyal (Y-kablo). Makara r=6 mm.
E. TETIK TAHRIK — ELEKTRIK | E2 | Servo Y-kablosu (1 giris -> 2 servo) | 1 | JR/Futaba 3 pin | ~15 cm | 4.0
E. TETIK TAHRIK — ELEKTRIK | E3 | Servo uzatma kablosu | 1 | JR/Futaba 3 pin | gerekli boy (tarete gore) | 5.0 | Ucus kontrolcusundeki bir PWM cikisina.
E. TETIK TAHRIK — ELEKTRIK | E4 | Tetik ipi | 2 | PE/Dyneema orgu, PE #6 (~0.40 mm, ~30 kg) | her biri ~120 mm | 0.0 | Pim deliginden -> kapak deliginden -> yonlendirme piminden -> servo tamburuna.
E. TETIK TAHRIK — ELEKTRIK | E5 | Kablo bagi / spiral | 4 | Naylon | 2.5 mm genislik | 0.4 | Kablolari namluya sabitlemek icin.
F. AG VE BILYELER | F1 | Ag ipi — goz + cevre halati + radyal baglar (HEPSI AYNI IP) | 1 | Hyper Dyneema orgu, O0.60 mm, 45.40 kg (ELDEKI IP) | altigen O2.2 m, kare goz 220 mm: 35.2 m kafes+halat + radyal baglar ve baglama paylari -> ~47 m kes | 12.9 | ELDE 90 m VAR — yeterli, 1 kez daha deneme payi birakir. Cevre halati icin ayri/kalin ip ALMA: ayni ip kullaniliyor.
F. AG VE BILYELER | F4 | Boncuk (bilye) | 6 | DELIKLI KURSUN boncuk — Captain 1216, O9 mm, 4 g/ad (ELDE VAR) | O9 mm, ortasi ~O2 mm delikli; yuva basina 1 ad (6 yuva) | 24.0 | ELDE VAR, satin alinacak degil. Delik sart: ip boncuklarin icinden gecer.
F. AG VE BILYELER | F5 | Kirilgan on kapak (her atis icin 1) | 1 | Ince kagit / pelur | O43 disk | 0.1 | Kapsul agzina yapistirici cubukla noktasal yapistirilir; bilyeleri ve ag paketini tutar, atista yirtilir.
G. SARF / YARDIMCI | G1 | Yag (pim yuzeyleri icin) | 1 | Ince makine yagi (veya PTFE kuru yaglayici sprey) | birkac damla | 0.0 | PTFE sprey surtunmeyi yagin ~yarisina indirir -> servoya ek pay.
G. SARF / YARDIMCI | G2 | Dis sabitleyici | 1 | Loctite 243 (orta) |  | 0.0 | Mil bileziklerinin set vidalari.
G. SARF / YARDIMCI | G3 | Siyanoakrilat yapistirici (CA) | 1 |  |  | 0.0 | TPU tampon, ankraj pimi uclari.
G. SARF / YARDIMCI | G4 | Yapistirici cubuk | 1 |  |  | 0.0 | Kirilgan kagit kapak icin (zayif tutunmali).
G. SARF / YARDIMCI | G5 | Talk pudrasi (opsiyonel) | 1 |  |  | 0.0 | Paketlenen agda iplerin birbirine yapismasini azaltir.
H. TEST / KURULUM EKIPMANI | H1 | Dijital bagaj kantari | 1 | 0-50 kg |  | 0.0 | Bant cekme testi + tetik ipi cekme kuvveti olcumu.
H. TEST / KURULUM EKIPMANI | H2 | Kurma eldiveni | 1 | Kalin is eldiveni |  | 0.0 | Her bant ~34 kg cekilir; tek tek takilir.
H. TEST / KURULUM EKIPMANI | H3 | Yedek bant seti | 1 | D1-D3 |  | 0.0 | Lateks yaslanir; testlerde surekli yedek bulundur.
H. TEST / KURULUM EKIPMANI | H4 | Yuksek hizli kamera (telefon 240 fps) | 1 |  |  | 0.0 | Yer atisinda acilma suresi/cap olcumu.

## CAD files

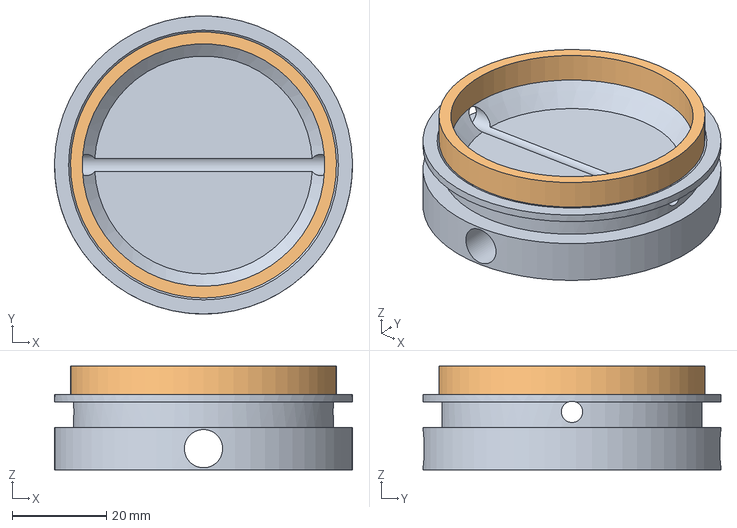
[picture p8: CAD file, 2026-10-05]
baski/02a_kapsul_alt.step
63.2 x 63.2 x 22.0 mm

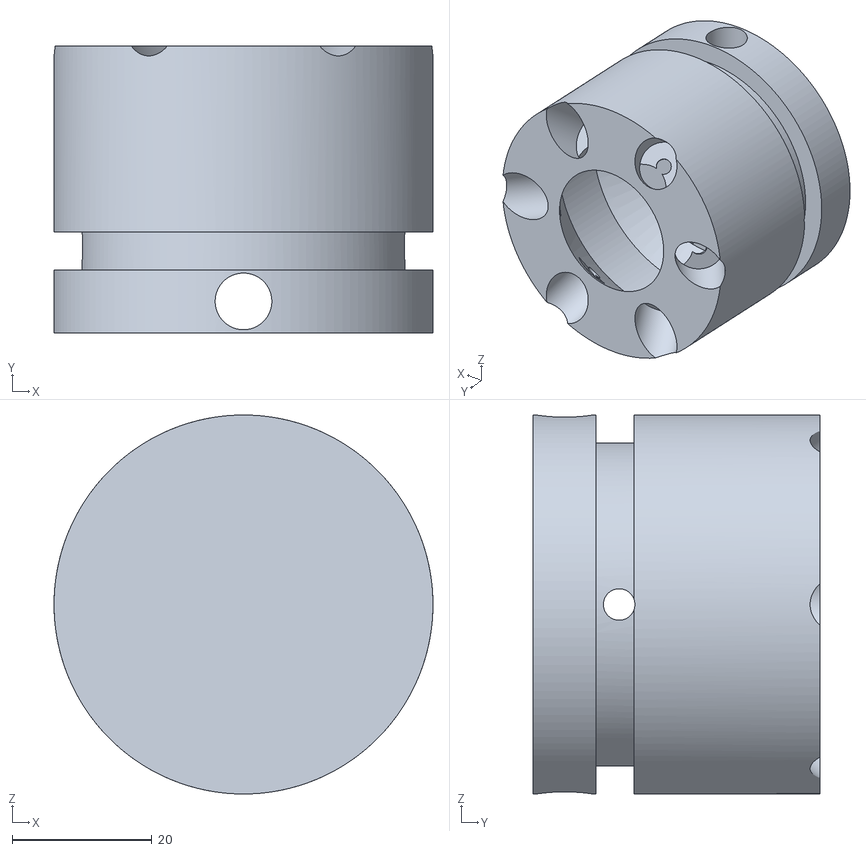
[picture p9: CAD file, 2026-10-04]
gazebo/models/ag_firlatici/meshes/kapsul.stl
54.2 x 41.0 x 54.2

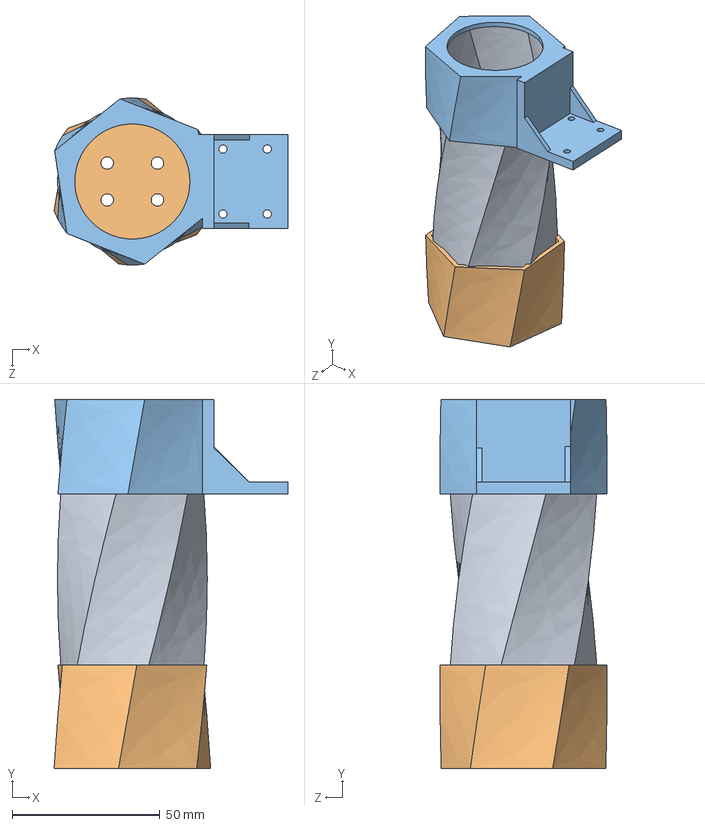
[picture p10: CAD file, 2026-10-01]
VAKKAS_NAMLU.STEP
79.2 x 125.0 x 56.5 mm
NAMLU_ALTIGEN_CAP30MM_UZUNLUK180MM_90DERECE_BURKULMUS
NAMLU_AGIZLIK_1
NAMLU_AGIZLIK_2

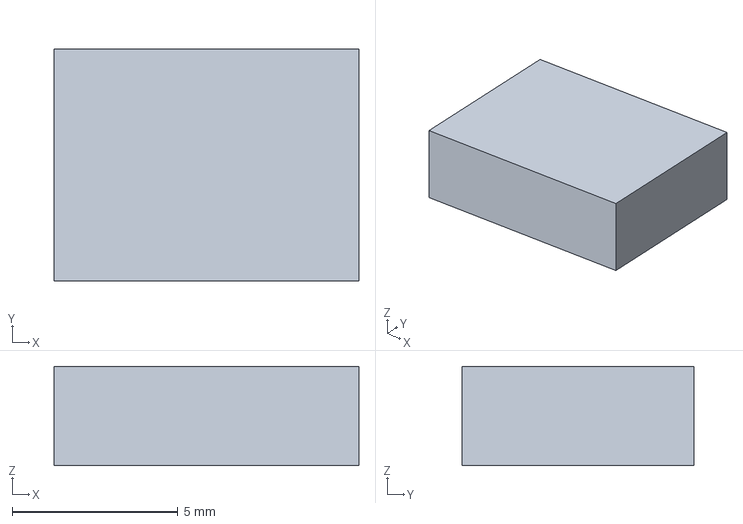
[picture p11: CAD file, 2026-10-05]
versiyonlar/v2.5/baski/08_tampon_alt.step
9.20 x 7.00 x 3.00 mm

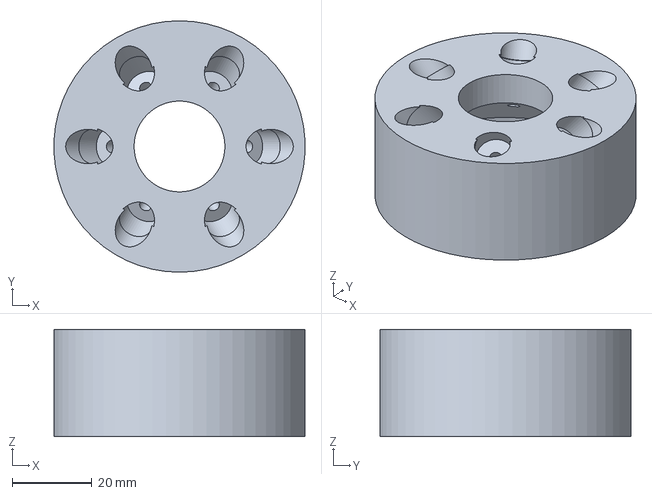
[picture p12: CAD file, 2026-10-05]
baski/02b_kapsul_ust.step
63.1 x 63.2 x 27.0 mm

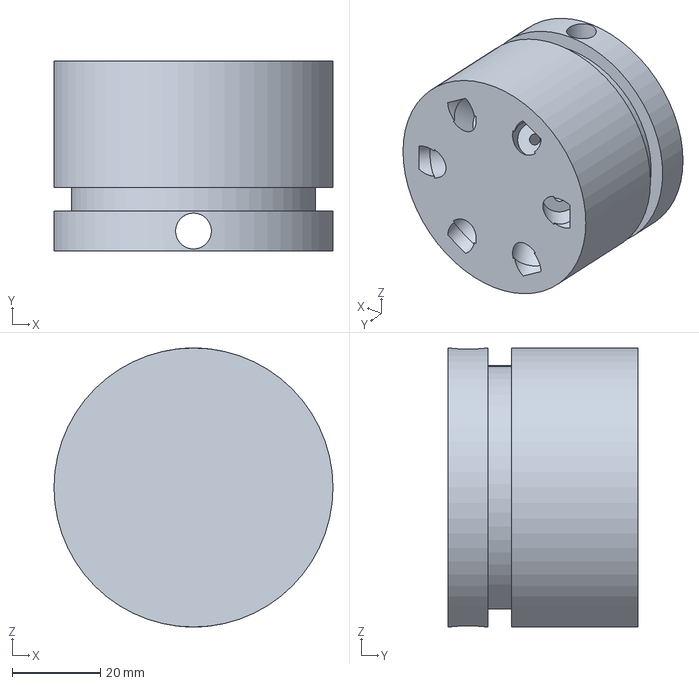
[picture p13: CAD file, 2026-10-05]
cad/V4_kapsul.step
63.2 x 43.0 x 63.2 mm

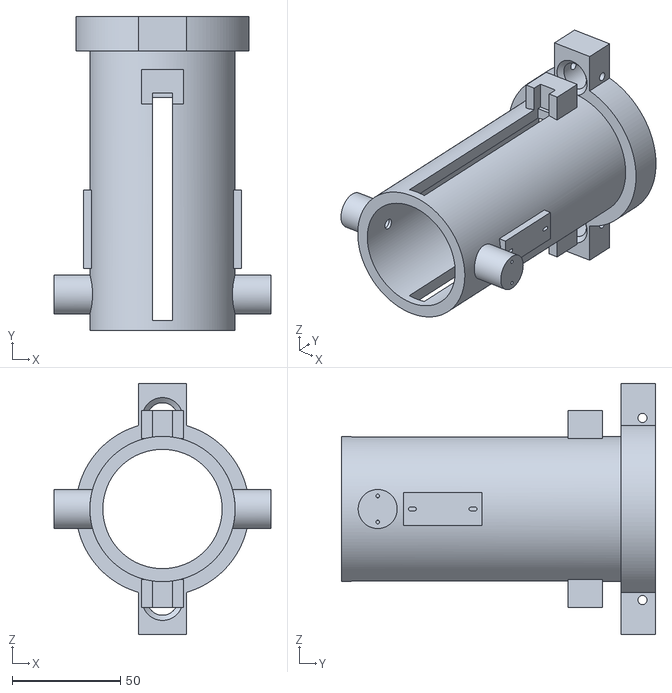
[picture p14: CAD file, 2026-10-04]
gazebo/models/ag_firlatici/meshes/namlu.stl
100.0 x 144.8 x 116.0

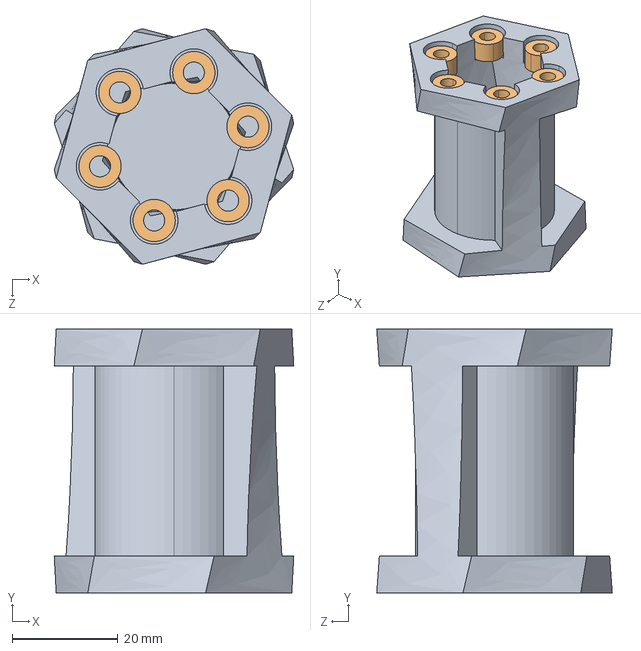
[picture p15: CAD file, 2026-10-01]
VAKKAS_NAMLU_ICI_AG_KAPSULU.STEP
45.4 x 50.0 x 44.6 mm
KAPSUL_ALTIGEN_CAP30MM_UZUNLUK50MM_90DERECE_BURKULMUS
8-2MM_AGIRLIK_AG x 6

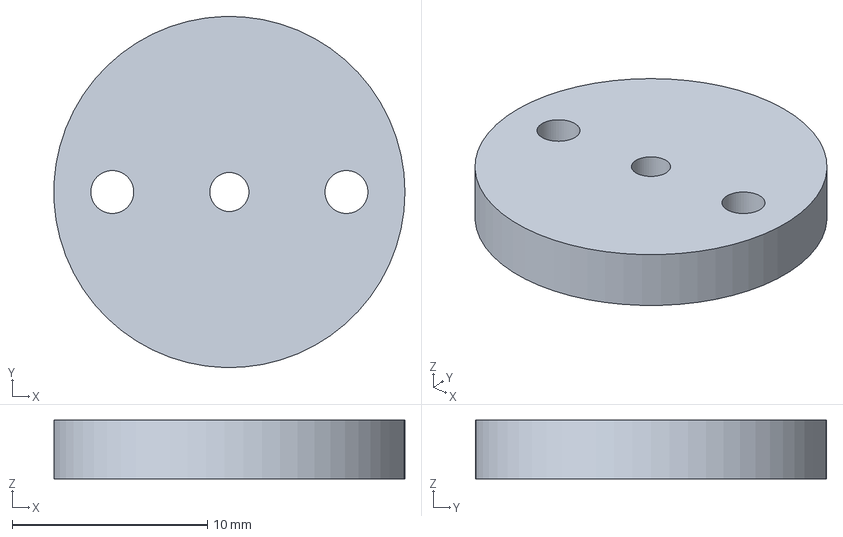
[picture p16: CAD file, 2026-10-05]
versiyonlar/v2.5/baski/03_tetik_kapagi_sag.step
18.0 x 18.0 x 3.00 mm

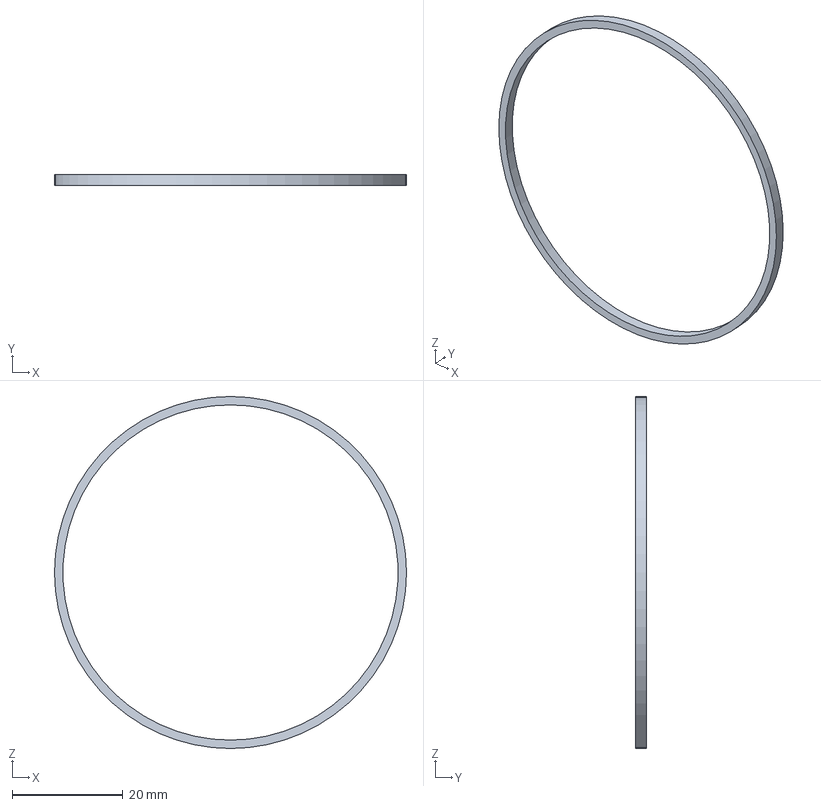
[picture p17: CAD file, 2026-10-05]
cad/V4_omuz_halkasi.step
63.6 x 2.00 x 63.6 mm

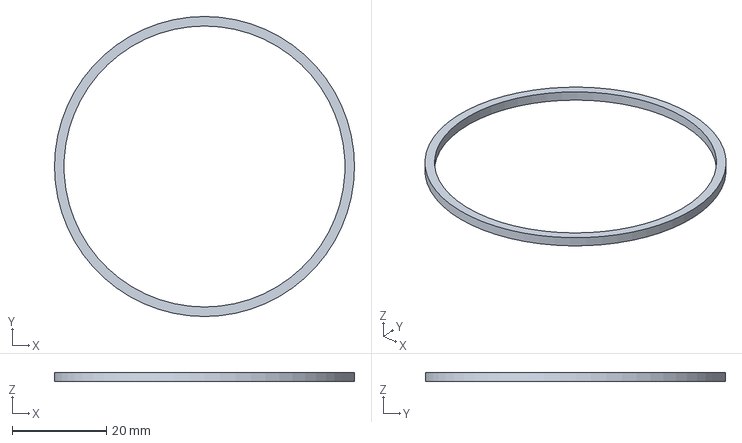
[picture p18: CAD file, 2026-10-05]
baski/10_omuz_halkasi.step
63.6 x 63.6 x 2.00 mm

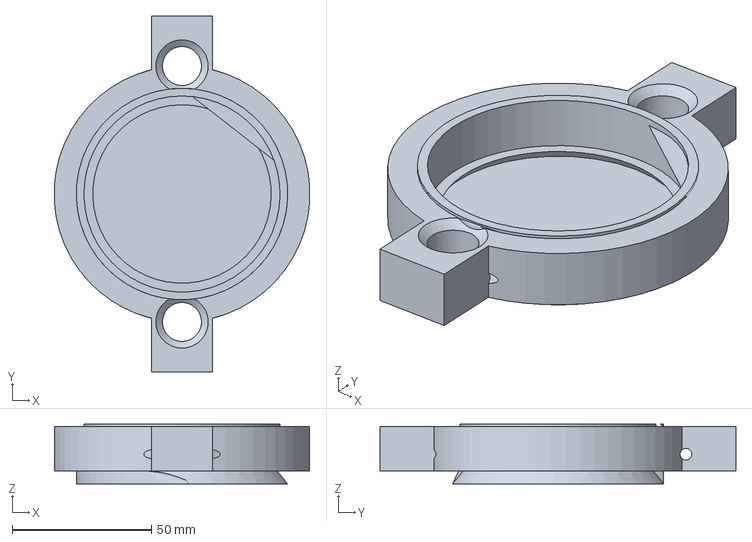
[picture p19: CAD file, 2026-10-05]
baski/01b_agiz_basligi.step
91.8 x 128.0 x 21.5 mm

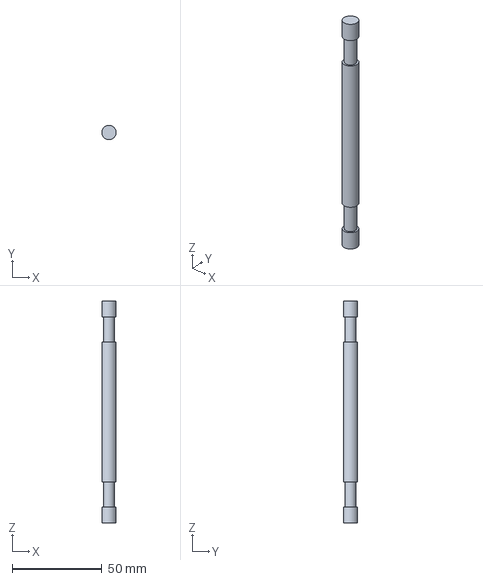
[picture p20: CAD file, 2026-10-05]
cad/V4_capraz_pim.step
7.99 x 8.00 x 124.0 mm

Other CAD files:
cad/V4_kapsul_alt.step
baski/07_tampon_ust.step
versiyonlar/v2.5/baski/07_tampon_ust.step
cad/V4_tampon_alt.step
baski/01a_namlu_govde.step
baski/01a_namlu_govde.stl
baski/01b_agiz_basligi.stl
baski/02a_kapsul_alt.stl
baski/02b_kapsul_ust.stl
baski/03_tetik_kapagi_sag.step
baski/04_tetik_kapagi_sol.step
baski/05_servo_makarasi.step
baski/06_toz_kapagi.step
baski/07_tampon_ust.stl
baski/08_tampon_alt.step
baski/08_tampon_alt.stl
baski/09_capraz_pim_TORNA.step
baski/10_omuz_halkasi.stl
baski/10_takoz_pad.step
cad/V4_MONTAJ.step
cad/V4_bant_1.step
cad/V4_bant_2.step
cad/V4_bilye.step
cad/V4_kapak_sag.step
cad/V4_kapak_sol.step
cad/V4_kapsul_hazneli.step
cad/V4_kapsul_ust.step
cad/V4_namlu.step
cad/V4_pim_sag.step
cad/V4_pim_sol.step
cad/V4_takoz_pad_1.step
cad/V4_takoz_pad_2.step
cad/V4_tampon_ust.step
versiyonlar/v1.1/baski/01a_namlu_govde.step
versiyonlar/v1.1/baski/01b_agiz_basligi.step
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

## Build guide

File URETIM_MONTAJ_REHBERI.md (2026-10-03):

# ÜRETİM VE MONTAJ REHBERİ — Ağ Fırlatıcı v5

> **Bu rehber üretilecek sistemin TAMAMINI kapsar.** Sırayla uygula.
> Her bölümün sonunda bir **KONTROL** maddesi var — geçmeden sonrakine geçme.

---

## 0. ÖNCE GÜVENLİK — bunu atlama

Bu mekanizma kurulduğunda **4 lateks bantta toplam ~1200 N (120 kg)** enerji
depolar. Kurulu haldeki kapsül bir mermidir.

| Kural | Neden |
|---|---|
| **Kurulu namluyu asla kimseye doğrultma** | Kapsül 31.1 m/s ile çıkar |
| **Kurarken koruyucu gözlük tak** | Bant kopması yüze gelir |
| **Kurma sırasında namlu ağzının önüne elini sokma** | Pim kayarsa kapsül fırlar |
| **Lateks yaşlanır** — 6 ayda bir değiştir, çatlak görürsen hemen | Kopan bant kırbaç gibi savrulur |
| **Taşırken kurma** — kurulum atıştan hemen önce | Sürünme (creep) hem gücü düşürür hem risk |
| **İlk atışları yerde, ağırlıklı bir kızakta yap** | Geri tepme ~75 N·s |

**Kurma sırasında pim güvenliği:** iki tetik pimi takılı ve mil bilezikleri
(B3) sıkılı olmadan bantları germeye başlama.

---

## 1. ÜRETİM SIRASI (toplam ~3 gün + baskı süresi)

```
GÜN 1  : 3D baskıları başlat (A1 namlu ~14 saat)
         paralel: ağ örmeye başla (~2.5 saat)
GÜN 2  : baskılar biterken metal parçaları ısmarla/işlet
         bant uçlarını hazırla (D1-D3)
GÜN 3  : mekanizma montajı + kuru deneme (banttsız)
         sonra bant takma + yer testi
```

---

## 2. 3D BASKI

### 2.1 Basılacak parçalar

> **Hepsi `baski/` klasöründe.** STL'ler **slicer'a hazır yöndedir** —
> tablaya oturtulmuş, ortalanmış. **Döndürme, sadece sürükle-bırak.**
> Tam ayarlar: **`baski/BASKI_AYARLARI.md`**

| Dosya | Parça | Adet | Filament | Filament | Süre |
|---|---|---|---|---|---|
| `01_namlu` | Namlu gövdesi | 1 | **PETG** | ~151 g | ~12 sa |
| `02_kapsul` | Kapsül | 1 | **PETG** | ~29 g | ~3 sa |
| `03/04_tetik_kapagi` | Tetik kartuş kapağı | 2 | **PETG** | ~2 g | 15 dk |
| `05_servo_makarasi` | Servo ip makarası | 2 | **PETG** | ~2 g | 15 dk |
| `06_toz_kapagi` | Arka toz kapağı (ops.) | 1 | **PETG** | ~6 g | 20 dk |
| `07/08_tampon` | Yarık sonu tamponu | 2 | **TPU 95A** | ~0.2 g | 10 dk |

> ⚠️ **DESTEK AYARI KRİTİK.** Namlu, ağzı AŞAĞI basılır ve Ø43 delik
> tablaya açıktır. Desteği öylece açarsan dilimleyici **deliğin içini de
> doldurur** — parça dışarıdan doğru görünür ama içi dolu çıkar (ilk
> baskıda bu oldu). Destek gerçekten gerekli olan tek yer tetik göbekleri
> ve servo yataklarıdır (yüzeyin %2.4'ü). **Deliğe destek engelleyici koy**
> ya da desteği tamamen kapat. Ayrıntı: `baski/BASKI_AYARLARI.md` §1.5.

**TOPLAM: PETG ~190 g · TPU ~0.2 g.** Yazıcı Z yüksekliği **≥155 mm** olmalı.

> `cad/V4_bilye`, `V4_capraz_pim`, `V4_bant_*`, `V4_pim_*` **BASILMAZ** —
> bunlar satın alınan parçaların CAD'deki temsilleridir (kurşun bilye,
> alüminyum çapraz pim, lateks tüp, çelik tetik pimi).

### 2.2 Baskı ayarları

**A1 — NAMLU (en kritik parça)**
```
filament     : PETG  (ASA varsa tercih et — UV dayanımı)
nozzle       : 0.4 mm      yatak: 80 °C     nozzle: 240 °C
katman       : 0.20 mm
duvar        : 4 çevre  (≥1.6 mm)        ← bant kulakları bunu taşıyor
üst/alt      : 5 katman
dolgu        : %50 gyroid
destek       : YOK  (yarıklar ve delikler kendini taşır)
YÖN          : DİK — namlu ekseni Z'de, ağız yukarı
soğutma      : %30 (PETG'de fazla soğutma katman yapışmasını bozar)
```
**Neden dik:** bant kulaklarına gelen 1200 N çekme, katman düzlemine
**paralel** olur. Yatay basarsan kuvvet katmanları ayırmaya çalışır ve
kulak kopar. Bu pazarlık konusu değil.

**A2 — KAPSÜL**
```
PETG, 0.20 mm, 5 çevre, %60 dolgu, destek YOK
YÖN: ağız YUKARI (bilye yuvaları üstte)
```
Arka blok 16 mm boyunca 1200 N'u çapraz pime aktarır — dolguyu kısma.

**A3 — TETİK KAPAĞI (2 adet)**
```
PETG, 0.15 mm katman, %100 dolgu, düz yatır
```

**A5 — TAMPON (2 adet)**
```
TPU 95A, 0.20 mm, %30 dolgu, yavaş (20 mm/s), retraction KAPALI
```

**A4 — SERVO MAKARASI (2 adet)**
```
PETG, 0.15 mm, %100 dolgu. Servo dişlisine geçen göbek
kendi servonun kolundan ölçülerek çizilmeli (marka farkı var).
```

### 2.3 Baskı sonrası
1. Namludaki **iki düz yarığı** (6.4 mm) eğeyle temizle — kapsül çapraz pimi
   buradan geçecek, takılma olmamalı.
2. Tetik pimi deliklerine **PTFE burcu (B7)** çakmadan önce deliği 5.0 mm
   matkapla raybala.
3. **M2 ısıl gömme insertleri (C1)** havyayla otur — 8 adet (4 kapak + 4 servo).
   Havya ucu 220 °C, yavaş bastır, dik tut.
4. Kapsülü namluya **boş** sok, serbest kayıyor mu bak. Takılıyorsa yarığı
   ve kapsül dış çapını zımpara ile al (hedef boşluk 0.3 mm).

**KONTROL:** Kapsül namlu içinde kendi ağırlığıyla kayıyor mu? Hayırsa devam etme.

---

## 3. SATIN ALMA LİSTESİ

Tam liste: `malzeme_listesi.md`. Özet alışveriş:

### Metal
- [ ] **B1** Alüminyum 7075 çubuk Ø8 mm, 100 mm (çapraz pim — oluklar torna/eğe)
- [ ] **B2** Gümüş çeliği/paslanmaz çubuk Ø5 mm, 50 mm (2 tetik pimi)
- [ ] **B3** Mil bileziği Ø5 iç / Ø10 dış, set vidalı — 2 adet
- [ ] **B4** Basma yayı: iç ≥5.3, dış ≤10.2, serbest ~13 mm — 2 adet
- [ ] **B5** Paslanmaz pim Ø4 × 16 mm — 4 adet (bant ankrajı)
- [ ] **B6** Paslanmaz pim Ø3 × 10 mm — 2 adet (ip yönlendirme)
- [ ] **B7** PTFE burç iç Ø5 / dış Ø7 × 10 mm — 2 adet

### Bağlantı
- [ ] **C1** M2×3 ısıl insert — 8 ad
- [ ] **C2** M2×6 civata — 4 ad   **C3** M2×8 civata — 4 ad

### Tahrik
- [ ] **D1** Zıpkın lastiği, **SAF DOĞAL KAUÇUK**, Ø15.2 dış / Ø4 iç — 4 × 50 mm
      (silikon veya EPDM **OLMAZ** — enerji yoğunluğu çok düşük)
- [ ] **D2** Dyneema örgü halat Ø1.5 mm — 60 cm
- [ ] **D3** Sargı ipliği (naylon dikiş) — 2 m

### Elektrik
- [ ] **E1** **MİKRO** metal dişli servo (≥3.5 kg·cm @6V, ~14 g, delik aralığı 28 mm) — 2 ad
- [ ] **E2** Servo Y-kablosu  **E3** uzatma kablosu

### Ağ
- [ ] **F1** Dyneema **ÖRGÜ** balık ipi PE #1 (~0.165 mm, 8-9 kg) — 50 m makara
- [ ] **F2** Dyneema **ÖRGÜ** PE #3 (~0.285 mm, 18 kg) — 10 m
- [ ] **F4** **DELİKLİ kurşun balık ağırlığı** ~12 g, Ø12.7 mm — 6 ad
- [ ] **F5** Pelur kâğıt (kırılgan kapak)

### Sarf
- [ ] İnce makine yağı veya **PTFE kuru yağlayıcı sprey** (tercih)
- [ ] Loctite 243, CA yapıştırıcı, yapıştırıcı çubuk, talk pudrası

### Test
- [ ] Dijital bagaj kantarı 0-50 kg
- [ ] Kalın iş eldiveni, koruyucu gözlük

---

## 4. AĞ ÖRME (~2.5 saat) — en çok emek isteyen iş

### 4.1 Ağın tanımı
```
dış hat : DÜZGÜN ALTIGEN, köşe yarıçapı 1.30 m  (karşılıklı köşe arası 2.60 m)
          altıgenin her kenarı = 1.30 m
göz     : KARE, 200 mm
mesh ipi: Dyneema ÖRGÜ Ø0.165 mm (PE #1)  — F1
çevre   : Dyneema ÖRGÜ Ø0.285 mm (PE #3)  — F2, 7.8 m
bağ     : ~142 (≈83 göz kesişimi + ≈59 çevre bağlantısı)
```

### 4.2 Şablon hazırla (bunu atlama — elde düzgün olmaz)
1. Yere **2.8 × 2.8 m** kontrplak/OSB ya da düz zemin al.
2. Üzerine tebeşir/bantla **düzgün altıgen** çiz: merkezden 1.30 m'de 6 köşe,
   60° aralıklarla. (Pratik yol: 1.30 m ipin ucuna kalem bağla, daire çiz;
   sonra daire üzerinde pergeli 1.30 m'ye açıp 6 eşit yay işaretle.)
3. Altıgenin içine **200 mm aralıklı kare ızgara** çiz — iki yönde.
4. Her ızgara çizgisinin altıgen kenarını kestiği noktaya **çivi/raptiye** çak.
   Bunlar ipleri gerili tutacak.

### 4.3 İpleri ser — DÜĞÜM ATMA, SADECE SER
1. **Tek parça** ipi bir kenardaki çividen karşı kenardaki çiviye çek, çiviye
   bir tur dola, **kesme**, geri dön. Böylece zikzak giderek tüm bir yönü ser.
   (~13 hat)
2. Aynısını **dik yönde** yap. (~13 hat)
3. Toplam **~26 sürekli ip**. Hepsi gergin ama **aşırı germe** — elle çekince
   1-2 mm esneyecek kadar.

> **NEDEN SÜREKLİ:** ip boyunca düğüm yoksa tam dayanımını (64 N) korur.
> Kesip düğümlersen 35 N'a düşer. Ayrıca sürekli ip paketten çok daha
> düzgün açılır (paraşüt ip hattı mantığı).

### 4.4 Kesişimleri bağla (~83 adet)
Her kare kesişimde iki ip üst üste geçer. Bunları **birbirine düğümleme** —
sadece **kaymayı önle**:

**Yöntem (en kolay ve sağlam): sargı bağı**
1. 15 cm'lik ayrı bir ince ip parçası al (F1'den).
2. Kesişimin üstüne **çapraz sar**: önce bir yöne 3 tur, sonra dik yöne 3 tur
   (cerrahi dikişteki "çapraz sargı" gibi).
3. Ucunda **iki yarım düğüm** (square knot) at, 2 mm bırakıp kes.
4. Üstüne **bir damla CA yapıştırıcı** — Dyneema'ya tam yapışmaz ama sargıyı
   kilitler.

**Alternatif (daha hızlı): tek kravat bağı**
Kesişimi parmakla tut, ince ipi bir kez dolayıp **constrictor knot** at.
Dyneema'da constrictor iyi tutar.

> **DÜĞÜM ATMA UYARISI:** iki mesh ipini birbirine **sheet bend** ile
> bağlarsan ipler kesilmiş olur ve dayanım yarıya iner. Kesişimler
> **bağdır, ek değildir**.

### 4.5 Çevre halatını ekle (F2, ~59 bağ)
1. Ø0.285 mm halatı altıgenin **6 kenarı boyunca** ser, köşelerde
   **tam 1.30 m** olacak şekilde. Toplam 7.8 m. Uçları köşede birleştir
   (double fisherman's bend).
2. Her mesh ipinin kenara ulaştığı yerde, ipi halatın etrafına
   **3-4 tur SAR** (lacing), sonra kendi üstüne iki yarım düğüm.
   **DÜĞÜMLE BAĞLAMA.**

> **NEDEN SARARAK:** düğümlü uç 35 N taşır, sarılmış uç ~64 N.
> Ölçülen tepe yük 19 N → pay 1.9× yerine **3.4×**.

### 4.6 Bilyeleri bağla (6 adet)
1. Her **kurşun bilyenin deliğinden** 70 mm'lik F2 ipi geçir.
2. Dışta **durdurma düğümü** (figure-8) at — bilye düşmesin.
3. Diğer ucunu çevre halatının **köşesine** sar + bağla.
4. Bilye ile köşe arası serbest boy: **40 mm**.

### 4.7 Ağ bitti — KONTROL
- [ ] Altıgen düzgün mü? Karşılıklı köşeler **2.60 ± 0.03 m**
- [ ] 6 bilye köşelerde, hepsi sağlam
- [ ] Çevre halatı kesintisiz, hiçbir yerde gevşek değil
- [ ] Hiçbir kesişim kayıyor mu? Eliyle it — kaymamalı
- [ ] **Tart: ağ + bilye ≈ 74 g** olmalı (ağ ~1 g, bilyeler ~73 g)

### 4.8 KATLAMA — dolanmanın asıl belirleyicisi
> Hazne 17.3 cm³; ağ paketi **%33 doluluk** ile rahat sığar. **Hacim sorun
> değil, DÜZEN sorun.** Rastgele tıkarsan hacim yetse bile açılmaz.

**Doğru yöntem (dışarıdan içeri, akordeon):**
1. Ağı yere tam açık ser, bilyeleri 6 köşeye yay.
2. Üzerine **ince talk pudrası** serp, elle dağıt (ipler birbirine yapışmasın).
3. **Merkezden başlayarak** ağı kendi üzerine **akordeon gibi** katla:
   her kat 35 mm genişliğinde olsun (hazne çapından küçük).
4. Katlanmış şeridi **merkez uçta, bilyeler dışta** kalacak şekilde
   rulo yap. **Bilyeler EN SON, en dışta.**
5. Haznenin içine **merkez önce** koy — yani açılırken **dış halka
   önce çıkacak** ("pay-out" düzeni).
6. Bilyeleri 6 yuvasına otur (13° koni yuvalar).
7. Ağzına **pelur kâğıdı (F5)** yapıştırıcı çubukla **noktasal** yapıştır —
   zayıf tutsun, atışta yırtılsın.

> **Bu adımı ilk seferde 3 kez tekrarla.** Katlayıp çıkar, bak nasıl açılıyor.
> Model bu kısmı HESAPLAYAMIYOR; tek doğrulama senin gözün.

---

## 5. LATEKS BANT HAZIRLAMA (4 adet)

> Her bant kurulduğunda **~300 N (31 kg)** çeker. Uç bağlantısı kaçarsa
> bant kırbaç gibi savrulur. Bu bölümü dikkatli yap.

### 5.1 Ölçü
```
tüp        : Ø15.2 dış / Ø4 iç, SAF DOĞAL KAUÇUK
kesim boyu : 50 mm   =  çalışma 30.3 mm (L0) + 2 × 10 mm uç bağlantısı
kurulu boy : 135.3 mm  (λ = 4.0 uzama)
```

### 5.2 Uç halkası (her tüpün iki ucuna, toplam 8 halka)
1. **D2** Dyneema halattan 60 mm kes, uçlarını **yakma** (eriyip sertleşir).
2. Halatı **halka** yap, düğümle (double fisherman's). Halka iç çapı ~8 mm.
3. Halkanın düğümlü kısmını tüpün ucundan **10 mm içeri** sok.
4. Tüpün dışından, halkanın üstüne gelen bölgeyi **D3 sargı ipliğiyle
   sıkıca sar** — 10 mm boyunca, tur tur, üst üste bindirerek.
5. Sargı sonunu iki yarım düğümle kilitle, **CA damlat**.
6. **Uç başına toplam donanım çapı 7 mm'yi geçmesin** — yoksa namlu
   yarığından geçmez.

### 5.3 Bant testi — ATLAMA
Her bandı tek tek, **bagaj kantarıyla (H1)** çek:
```
boy 101 mm (λ=3.0) → ~184 N (18.8 kg) beklenir
boy 135 mm (λ=4.0) → ~300 N (30.6 kg) beklenir
```
- Ölçtüğün değer beklenenin **%25 altındaysa** tüp saf lateks değildir, kullanma.
- Çekerken **uç bağlantısı kayıyorsa** sargıyı yenile.
- Dört bandın kuvveti birbirinden **%10'dan fazla farklıysa** eşleştir
  (en yakın ikisini karşılıklı kenarlara koy) — asimetrik itme nişanı kaydırır.

---

## 6. MEKANİZMA MONTAJI

### 6.1 Tetik kartuşları (2 adet, namlunun iki yanında)
```
Sıra: PTFE burç → pim → yay → mil bileziği → kapak
```
1. **B7 PTFE burcu** namlunun tetik göbeğindeki deliğe çak (hafif sıkı geçme).
2. **B2 tetik pimini** burçtan geçir. Pimin **uç ucu** kapsül kanalına girecek.
3. Pimin dış ucundaki Ø1.5 mm delikten **E4 tetik ipini** geçir, düğümle.
4. **B4 yayını** pime geçir (kapağa dayanacak).
5. **B3 mil bileziğini** pim üzerinde **uçtan 12.2 mm**'ye getir, M3 set
   vidasını **Loctite 243** ile sık.
   > Dinlenmede pim ucu kanal dibine **0.3 mm** pay bırakmalı.
6. **A3 kapağı** M2×6 civatalarla (C2) insertlere tuttur. İp kapağın
   ortasındaki Ø2 delikten çıkıyor olmalı.
7. **G1 yağını** pime birkaç damla / PTFE sprey sık. Pimi elle it-çek:
   **pürüzsüz** hareket etmeli, takılırsa sök ve zımpara.

### 6.2 Servolar
1. **E1 servoyu** namlunun yan yatağına otur, M2×8 (C3) ile insertlere vidala.
2. **A4 makarasını** servo dişlisine geçir, servonun kendi kol vidasıyla sık.
3. **B6 yönlendirme pimini** kapak ile servo arasındaki deliğe çak.
4. Tetik ipini: **kapak deliği → yönlendirme pimi → servo makarası**
   yolundan geçir, makaraya 2 tur dola, düğümle.
5. İki servoyu **E2 Y-kablosuyla** birleştir — **AYNI SİNYAL** almalılar.

> **⚡ GÜÇ UYARISI:** iki servonun stall akımı ~2.5 A/adet = **5 A toplam**.
> İnce Y-kablo ve alıcı regülatörü bunu kaldırmaz, yanar.
> **Y-kabloyu yalnızca SİNYAL için kullan; +5V ve GND'yi her iki servoya
> doğrudan BEC'ten çek.**

> **Servo seçimi:** **MİKRO metal dişli servo** kullanılıyor (Savöx
> SH-0255MG / MG92B sınıfı, ~14 g, ≥3.5 kg·cm). MG996R (55 g) gereksiz
> ağırdı. Makara **r=2.2 mm** ve kanal derinliği 4 mm olduğu için gereken
> tork **2.15 kg·cm** → **1.81× pay**.
> **Makarayı büyütme** — r=4 mm'de tork 3.9 kg·cm'ye çıkar ve mikro servo yetmez.
> **METAL DİŞLİ ŞART** — mikro servoların plastik dişlileri sıyırır.

### 6.3 Servo ayarı (bantlar TAKILI DEĞİLKEN)
1. Uçuş kontrolcüsünden servoya **"dinlenme"** konumu ver → iki pim de
   **tam içeride** (kapsül kanalına girmiş).
2. **"Ateş"** konumu ver → iki pim de **tam dışarıda** (kanaldan çıkmış).
3. İkisi **aynı anda** çıkıyor mu? Gecikme varsa servo kollarının
   açısını eşitle. **Asimetrik çekiş kapsülü yana kaydırır.**
4. Pim stroku: en az **5 mm** (kanal derinliği 4 mm + pay). Servo dönüşü ~130°.

### 6.4 Tampon ve çapraz pim
1. **A5 TPU tamponlarını** namlunun iki yarığının **ön ucuna** CA ile yapıştır.
   Kapsülün çapraz pimi buraya çarparak duracak (~450 N).
2. **B1 çapraz pimini** kapsülün arka bloğundaki Ø8 deliğe geçir.
   Her iki ucu yarıklardan **eşit** çıkmalı (46 mm / 46 mm).

**KONTROL:** Bantsız, kapsülü elle namluda ileri-geri kaydır. Çapraz pim
yarıklarda takılmadan gidiyor mu? Tamponlara temas ediyor mu?

---

## 7. KURMA (COCKING) — en riskli işlem

> **Gözlük tak. Eldiven giy. Namlu ağzını kimseye doğrultma.**

### 7.1 Sıra
1. **Ağ yüklü kapsülü** namluya arkadan sok (§4.8'deki gibi paketlenmiş).
2. Kapsülü **strok sonuna kadar** (91 mm) geriye it — çapraz pim
   arka konuma gelsin.
3. **Servoları "dinlenme"ye al** → iki pim kapsül kanalına girsin.
   **Pimlerin girdiğini GÖZLE DOĞRULA.** Kapsülü elle ileri itmeye çalış,
   kıpırdamamalı.
4. Şimdi bantları tak — **tek tek, karşılıklı sırayla**:
   ```
   1. bant: üst-sağ     2. bant: alt-sol   (karşılıklı)
   3. bant: üst-sol     4. bant: alt-sağ
   ```
   Her bandın:
   - **arka halkası** → çapraz pimin oluğuna (r=33 ve r=44 mm olukları)
   - **ön halkası**  → ağız kulağındaki **B5 ankraj pimine**
5. Her bandı takarken **eldivenle ~31 kg** çekeceksin. Kısa bir kol/kanca
   kullanmak işi kolaylaştırır.
6. Dört bant da takıldıktan sonra **simetriyi kontrol et**: kapsül namlu
   ekseninde mi, yana kaçmış mı?

### 7.2 Kurulu sistem kontrolü
- [ ] İki tetik pimi de tam içeride
- [ ] Dört bant da ankraj pimlerinde, hiçbiri oluktan kaçmamış
- [ ] Kapsül eksende, yana yatmamış
- [ ] Çapraz pim iki yarıktan eşit çıkıyor
- [ ] Ön kapak (pelur kâğıt) yerinde
- [ ] **Namlu ağzı güvenli yöne bakıyor**

### 7.3 Ateşleme
Uçuş kontrolcüsünden servolara **"ateş"** sinyali → iki pim aynı anda
çekilir → kapsül 31.1 m/s ile çıkar → çapraz pim tamponlara çarpıp durur →
ağ ve bilyeler devam eder.

> **Kapsül namlu içinde kalır** — dışarı çıkan sadece ağ + 6 bilyedir.

---

## 8. YER TESTİ — uçuşa geçmeden ÖNCE

> Modelin **cevaplayamadığı tek şey dolanmadır**. Bu testler onu çözer.
> Hiçbirini atlama.

### T1 — Kuru tetik testi (bantsız, ağsız)
Servolara 20 kez ateş/dinlenme ver. Her seferinde iki pim **aynı anda**
tam çıkıp tam giriyor mu? Takılma varsa yağla/zımparala.
**Geç: 20/20.**

### T2 — Tek bant atışı (ağsız, boş kapsül)
1. Sadece **1 bant** tak (λ=4.0). Kapsül boş.
2. Namluyu bir kum torbasına doğrult, 5 m mesafe.
3. Ateşle. Kapsül tamponlara çarpıp **namluda kalmalı**.
4. Tamponlara, yarık uçlarına, ankraj pimlerine bak — çatlak var mı?

**Geç: hasar yok, kapsül namluda.**

### T3 — Tam kurulum, ağ ile YER ATIŞI  ★ en önemli test
1. Dört bant takılı, ağ §4.8'deki gibi paketlenmiş.
2. Namluyu **yukarı 30°** eğik, açık alana doğrult.
3. **Telefonla 240 fps** çek (H4).
4. Ateşle.

**Videodan ölç:**
| Ölçüm | Beklenen (model) | Senin ölçümün |
|---|---|---|
| Ağın tam açıldığı süre | ~200 ms | |
| En geniş çap | ~2.3 m | |
| Dolanma var mı? | YOK olmalı | |
| Kaç bilye serbest? | 6/6 | |

**Geç şartı:** ağ **dolanmadan** açılıyor ve çapı **≥1.8 m**'ye ulaşıyor.
- Dolanıyorsa → §4.8 katlamayı değiştir, talk pudrasını artır, tekrar dene.
- Açılmıyorsa → bilye bağ iplerinin (F3) 40 mm serbest boyunu kontrol et.

> **Bu testi en az 3 kez tekrarla.** Üçünde de temiz açılmadan uçuşa geçme.

### T4 — Statik hedef testi
1. Talon'u (ya da 1.7 m kanat açıklığında bir maket) yere/sehpaya koy.
2. **4.2 m** mesafeden ateşle (bkz. §9 — en iyi tetikleme mesafesi).
3. Ağ uçağı sarıyor mu? Pervaneye ip değiyor mu?
4. Pervaneyi elle döndür — ağ sarılıp kilitliyor mu?

### T5 — Pervane kesme testi  (modelin çözemediği ikinci şey)
1. Ağ ipinden 30 cm al, pervane kanadına sar.
2. Bagaj kantarıyla **~15 N** ger.
3. Motoru **düşük gazda** çalıştır (güvenli mesafeden, uçağı sabitle).
4. **İp kesiliyor mu, yoksa sarılıp motoru durduruyor mu?**

**Beklenen:** sarılıp durdurur. Kesiliyorsa → ipi Kevlar'a çevirmeyi
değerlendir (enine dayanımı 2.5× daha iyi).

### T6 — Bant yaşlanma kontrolü
Kurulu sistemi **30 dakika** bekletip ateşle. Çıkış hızı gözle belirgin
düştüyse lateks sürünüyor demektir → **kurulumu atıştan hemen önce yap**.

---

## 9. TETİKLEME MESAFESİ — Gazebo ölçümü

Geometrik pencere (ağın yeterince açık olduğu aralık) **3.6 – 6.8 m**,
ama **gerçek yakalama kalitesi mesafeyle hızla düşüyor**:

| tetikleme | ağın uçağa serilme oranı | aktarılan momentum | ip tepe yükü |
|---|---|---|---|
| 3.6 m | **%78** | 2.08 kg·m/s | 25.8 N |
| **4.2 m** | **%52** | 1.64 kg·m/s | 19.0 N |
| 5.0 m | %28 | 0.64 kg·m/s | 14.2 N |
| 5.8 m | %37 | 0.87 kg·m/s | 5.5 N |
| 6.5 m | %30 | 0.45 kg·m/s | 10.3 N |
| 7.0 m | %24 | 0.37 kg·m/s | 5.9 N |

**ÖNERİ: 4.0 – 4.5 m'den ateşle.**
- Uzakta ağ **yeterince açık** ama uçağın üzerinden **değip geçiyor**
- Yakında daha iyi sarıyor ama ip yükü artıyor (3.6 m'de 25.8 N)
- 4.2 m'de serilme %52, yük 19 N → **lacing** (sararak bağlama) ile pay 3.4×

> **DİKKAT — bu, önceki tavsiyemin TERSİ.** Daha önce "pencerenin uzak
> yarısından ateşle, ip yükü düşük olsun" demiştim. Gazebo'nun temas
> simülasyonu gösterdi ki uzakta ağ **yakalamıyor**. Python modeli sadece
> "ağ yeterince açık mı" diye bakıyordu; bu gerekli ama yeterli değilmiş.

**Tetikleme gecikmesi:** servo pimi ~120 ms'de çeker. 100 km/h'te bu
**0.77 m** demektir → hedef **5.0 m**'deyken tetikle ki ağ **4.2 m**'de
karşılasın.

---

## 10. UÇUŞ TESTİ

> **Simülasyonda önce dene.** Fırlatıcının monte edilebilir Gazebo model
> paketi hazır: `gazebo/models/ag_firlatici/`. Ateşleme `gz topic` ile
> tetiklenir.
>
> ⚠️ **İKİ PARÇA gerekiyor:** (1) `<include>` ile model paketi,
> (2) `gazebo/worlds/ag_eklentisi.sdf` içeriğini kendi `<world>`'üne
> **yapıştır** — ağ ve plugin model paketinin İÇİNDE DEĞİL. Sadece
> `<include>` yaparsan namlu görünür ama **ateş etmez**.
>
> Montaj arayüzü, ortam değişkenleri, kontrol listesi ve bilinen tuzaklar:
> **README §9 "Başka bir araca entegrasyon"**.

### Sıra
1. **Taret/gövde montajı** — namlu drona bağlanır (taret tasarımı henüz
   yapılmadı; şimdilik sabit, aşağı-ileri bakan bir yatak yeterli).
   Model paketindeki **`montaj`** çerçevesi (namlu ortası, üst yüzey)
   bağlantı referansıdır; **`agiz`** çerçevesi tetikleme mesafesinin
   ölçüldüğü noktadır.
2. **Boş atış** (ağsız, tek bant) — uçuşta geri tepmenin dronu nasıl
   etkilediğini gör. Geri tepme toplam **~75 N·s**.
3. **Ağlı atış, hedefsiz** — havada açılmayı doğrula.
4. **Hedefli atış** — Talon ile.

### Geri tepme hakkında
Kapsül namluda durduğu için momentum kapsülle birlikte namluya geri döner.
Net dışarı atılan momentum = ağ + bilyeler = 74 g × 31.1 m/s ≈ **2.3 kg·m/s**.
2 kg'lık bir dronda ~1.2 m/s hız değişimi — uçuş kontrolcüsü bunu bir
bozucu olarak görecek.
Tail-sitter için tek atışlık bir itme; nişan kayması önemsiz (tek atış
yapılıp inilecek).

---

## 11. SORUN GİDERME

| Belirti | Olası sebep | Çözüm |
|---|---|---|
| Ağ dolanıp açılmıyor | Rastgele paketleme | §4.8 akordeon katlama, talk pudrası |
| Ağ yarım açılıyor | Bilye bağ ipi kısa/uzun | F3 serbest boyu 40 mm'ye ayarla |
| Kapsül yana kaçıyor | Bantlar eşit değil | Bantları kuvvete göre eşleştir, karşılıklı tak |
| Tek pim geç çekiyor | Servo kolları farklı açıda | §6.3 servo ayarını tekrarla |
| Pim takılıyor | Yağsız / burç dar | PTFE sprey; deliği raybala |
| Bant ankrajdan kaçıyor | Uç sargısı gevşek | §5.2 sargıyı yenile, CA damlat |
| Kulak çatlıyor | Namlu YATAY basılmış | Dik bas (§2.2) — katman yönü kritik |
| Çıkış hızı düşük | Lateks yaşlanmış/sahte | Bagaj kantarıyla test (§5.3) |
| Ağ hedefe değip geçiyor | Çok uzaktan ateşlendi | 4.0–4.5 m'den ateşle (§9) |

---

## 12. SİSTEM ÖZETİ — ne ürettiğin

```
NAMLU      : Ø55.4 dış × 149.8 mm, PETG, düz delik, arkadan yüklemeli
TAHRİK     : 4 × lateks tüp Ø15.2/4, kurulu λ=4.0, toplam ~1200 N
STROK      : 91 mm
KAPSÜL     : Ø43.1 × 38 mm, 6 bilye yuvası (13° koni), ağ haznesi Ø37.1 × 14
TETİK      : 2 karşılıklı çelik pim, PTFE burç, 2 × MG996R servo, Y-kablo
AĞ         : altıgen Ø2.6 m, KARE göz 200 mm, Dyneema örgü Ø0.165
             + çevre halatı Ø0.285, ~142 bağ, ~26 sürekli ip
BİLYE      : 6 × Ø12.7 delikli kurşun, ~12 g
KÜTLE      : ~390 g (servolar dahil)

PERFORMANS (Gazebo + Python, doğrulanmış)
  çıkış hızı       : 31.1 m/s
  açılma           : 200 ms'de R = 1.13 m  (gereken 0.859)
  geometrik pencere: 3.56 – 6.54 m
  EN İYİ TETİKLEME : 4.0 – 4.5 m
  ip tepe yükü     : 19 N  (lacing ile pay 3.4×, düğümle 1.9×)
  kopan eleman     : 0
```

---

## 13. DOĞRULANMAMIŞ — bunları test edeceksin

Modelin **söyleyemediği** üç şey var. Üçü de yer testiyle çözülür:

1. **Ağın dolanmadan açılması** (§T3) — rijit-cisim çözücüsü ipin ipe
   takılmasını modelleyemez. **En kritik belirsizlik.**
2. **Pervanenin ipi kesip kesmediği** (§T5) — kesme eşiği modelle
   belirlenemiyor; eğilim biliniyor, mutlak değer bilinmiyor.
3. **Düğüm/lacing verimi** — %55 (düğüm) ve %90 (lacing) literatür tahmini.
   Gerçek numuneyle çekme testi yap.

Ayrıca **taret tasarımı henüz yapılmadı** (senin isteğinle ertelendi).

---

## 14. HIZLI KONTROL LİSTESİ (atış öncesi, her seferinde)

- [ ] Gözlük takıldı
- [ ] Ağ §4.8'e göre katlandı, talk pudrası uygulandı
- [ ] 6 bilye yuvalarında
- [ ] Pelur kâğıt kapak yapıştırıldı
- [ ] Kapsül strok sonuna itildi
- [ ] **İki pim de kanala girdi** (gözle doğrulandı)
- [ ] Kapsül elle itilince kıpırdamıyor
- [ ] 4 bant takılı, hiçbiri oluktan kaçmamış
- [ ] Kapsül eksende
- [ ] Namlu ağzı güvenli yönde
- [ ] Servolar Y-kablodan aynı sinyali alıyor

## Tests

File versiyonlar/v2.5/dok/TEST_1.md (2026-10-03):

# TEST 1 — İLK GERÇEK ATIŞ (6 boncuk · 2 bant)

> Bu doküman `out/TASARIM_V9.md`'nin yerine geçer. Fark: boncuk 12→**6**,
> yuva eğimi 30°→**40°**, bant 4→**2** (ilk test).
> Amaç menzil rekoru değil; **simülasyonun nerede yanıldığını görmek.**

---

## 1. NEDEN 40° — BU DEĞİŞMEZ

Boncuk 12'den 6'ya inince köşe başına kütle 8 g→4 g düşüyor. Ağı açan şey
hız değil köşelerin **radyal momentumu**; kütle yarıya inince açıyı
artırıp telafi etmek **zorunlu**:

| yuva eğimi | 6 boncuk + 2 bant, açılma payı |
|---|---|
| 30° | 0.91–1.02× → **ağ açılmaz** |
| 35° | 0.99–1.10× → yumuşak bantta açılmaz |
| **40°** | **1.08–1.17× → her sertlikte açılır** |
| 45° | 1.14–1.22× (menzil kısalır) |

30°'de basarsan ağ kanat açıklığını örtmez. Eski STL'ler 30°'ydi; **yeniden bas.**

---

## 2. BEKLENEN SONUÇ (2 bant)

Bant sertliği hâlâ ölçülmedi, o yüzden aralık olarak:

| Gmod | kurma kuvveti | çıkış hızı | açılma yarıçapı | pay | ağ açıkken mesafe |
|---|---|---|---|---|---|
| 0.25 MPa | 237 N (24 kg) | 17.4 m/s | 0.925 m | 1.08× | 0.50 – 0.84 m |
| 0.35 MPa | 331 N (34 kg) | 20.7 m/s | 0.957 m | 1.11× | 0.67 – 0.92 m |
| **0.45 MPa** | **426 N (43 kg)** | **23.5 m/s** | **0.980 m** | **1.14×** | **0.80 – 0.98 m** |
| 0.65 MPa | 615 N (63 kg) | 28.3 m/s | 1.007 m | 1.17× | 0.87 – 1.06 m |

Gereken açılma yarıçapı 0.859 m (Talon yarı kanat açıklığı).
Ağ **~90 ms**'de tam açılır, ~50 ms açık kalır, sonra çevre halatı boncukları geri çeker.

4 banda çıkınca: kurma 473–1230 N, hız 24.4–39.4 m/s, mesafe 0.84–1.31 m.

---

## 3. BANDI NASIL BAĞLAYACAKSIN — DYNEEMA YOK, PİM VAR

Ankraj yeniden tasarlandı: **bant deliğin içinden geçer, tailini bir pim deler.**
Eski 5.6 × 9 mm yuva ve Dyneema halka kaldırıldı.

### Ağız bileziği (ön uç)
- Her kenarda **Ø14 mm delik**, namlu ekseni boyunca, bilezikten baştan sona (16 mm).
- Deliğin arka ağzında **2.5 mm pah** — gergin bant kenarda kesilmesin.
- Bileziğin ön yüzünde **5.4 mm genişlik × 2.8 mm derinlik oluk**, taşıyıcı pim oraya oturur.
- Kulak kalınlığı 14 → **22 mm** (Ø14 deliğe her yandan 4 mm cidar).
- Ankraj yarıçapı 33 → **36 mm** (delik ıraksak koniyi delmesin diye).

**Bilezik artık y = 144.8'de bitiyor** (eskiden namlu ağzına kadar gidiyordu).
Bu kasıtlı: pim tam tasarımın ankraj noktasına oturuyor, böylece **L0, H ve λ
değişmiyor** — yukarıdaki hız/menzil tablosu aynen geçerli.

**Takma:**
1. Bandı arkadan Ø14 delikten geçir, ön yüzden **45 mm** çıkar.
2. Çıkan tailin ucundan **25 mm** içeride, bandı çapraz **del** (Ø5 matkap veya sivri mil).
3. **Ø5 × 30 mm çelik pimi** delikten geçir, oluğa yatır.
4. Bandı geri çek — pim oluğa oturur, kilitlenir.

### Çapraz pim (arka uç)
- Oluk 2.4 mm → **14 mm genişliğe** açıldı, Ø13 bant oturuyor.
- Çapraz pim 92 → **100 mm** uzatıldı (oluk sonuna pay).

**Takma:**
1. Bandı çapraz pimin oluğuna sar.
2. Tail'i **30 mm** geri katla, ana kolun yanına yatır.
3. Çapraz pimin ~15 mm arkasında, **ana kol + tail'i birlikte del**.
4. **Ø4 × 25 mm pimi** geçir.

### Dayanım kontrolü

| | 0.45 MPa (213 N/bant) | 0.65 MPa (308 N) |
|---|---|---|
| Ø5 pim eğilme (en kötü: nokta yük) | 61 MPa — **SF 6.6×** | 88 MPa — SF 4.6× |
| PETG oluk yatak basıncı | 5.3 MPa — **SF 9.4×** | 7.7 MPa — SF 6.5× |
| Lastik yırtılma (25 mm kenar mesafesi) | 0.47 MPa — kauçuk ~3–5 MPa | 0.68 MPa |

Bant sıyrılmaz: tail gergin değil, Ø13 kalır; pim 30 mm > delik 14 mm.
(Gergin kol λ=4'te Ø6.5'e incelir, delikten rahat geçer.)

**Riskli olan tek şey:** pim deliği lastikte çentik yaratır, kauçuk çentiğe
duyarlıdır. Birkaç atış için sorun yok; **her kurmadan önce pim bölgesine bak**,
yırtık başlangıcı görürsen tail'i kesip yeniden del.

### Bant kesim boyu
Kol başına **130 mm** (30 çalışma + 45 ön + 55 arka pay). **2 kol = 260 mm.**

### 2 bant nereye
Kenar başına **1 bant**: z = **+36** ve **−36** mm. Simetri şart.
(Ø13 bant + Ø14 delikle kenar başına ikinci ankraj sığmıyor; 4 bant istersen
çapraz pim ve kulaklar büyümeli.)

## 4. TESTTE MUTLAKA ÖLÇ

Simülasyonun doğrulanması için şunlar lazım:

1. **BANT SERTLİĞİ** — tek kol 50 mm kes, kantarla 135 mm'ye çek, kuvveti yaz.
   `Gmod [MPa] = F [N] / 308`. Bu tek sayı yukarıdaki tablonun hangi satırında
   olduğunu söyler. **Bunu atlarsan test yorumlanamaz.**
2. **KURMA KUVVETİ** — kapsülü geri çekerken kantarı araya koy, tepe değeri yaz.
   Tabloyla karşılaştır.
3. **ÇIKIŞ HIZI** — telefonla 240 fps çek, namlu ağzına 100 mm'lik bir cetvel
   koy, kareler arası yer değiştirmeden hesapla.
4. **AÇILMA ÇAPI ve MESAFESİ** — yere 0.5 m aralıklarla şerit çek, yandan çek.
   Ağ en geniş halindeyken: çapı kaç, namludan kaç metre ötede?
5. **AÇILDI MI, DOLAŞTI MI** — en kritik soru. Simülasyon ağın dolaşmasını
   hiç modellemiyor. Dolaşırsa nerede dolaştığını not et (köşeler mi, merkez mi).

### Not düşülecek şeyler (simülasyon bunları bilmiyor)
- Ağın kapsülden çıkış sırası düzgün mü, yoksa topak halinde mi çıkıyor
- Boncuklar yuvadan aynı anda mı çıkıyor
- Kapsül namluda sıkışıyor mu, tamponlara nasıl çarpıyor
- Bant ankrajı kayıyor mu

---

## 5. GÜVENLİK

- Kurulu sistem **426 N** depoluyor. Namlu ağzının önüne **asla** geçme.
- İlk kurmayı ağ/boncuk **takmadan** yap, tetiği boşa çalıştır.
- Gözlük tak. Boncuk 4 g × 23 m/s = ciddi.
- Kapsül arkasında kimse durmasın — çapraz pim kırılırsa geriye gider.

---

## 6. BASILACAK PARÇALAR

`baski/` klasörü **40° ve 6 boncuk** için yeniden üretildi.
Eski 30°/12 boncuk STL'leri geçersiz.

| Dosya | Değişti mi |
|---|---|
| `01a_namlu_govde.stl` | hayır (gövde aynı) |
| `01b_agiz_basligi.stl` | **EVET** — koni 30°→40° **+ yeni bant ankrajı** |
| `02_kapsul.stl` | **EVET** — yuva 40°, R_pitch 15.5, tek boncuk |
| `V4_capraz_pim` (alüminyum, torna) | **EVET** — oluk 14 mm, boy 100 mm |
| diğerleri | hayır |

Gövdeyi zaten bastıysan tekrar basmana gerek yok; **başlık + kapsül** yeter.

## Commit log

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2026-10-01 CAD: parametrik montaj ve BASKIYA HAZIR parcalar
    cad/lastik_montaj_v4.py tum geometri v4_konfig.json'dan turetiliyor
    (FreeCAD 0.19 headless, OpenCascade)
    cad/baski_parcalari.py baski parcalarini uretir -> baski/
    cad/ciz_torna_resmi.py tornaciya verilecek olculu teknik resim
    baski/ 8 parca, STL + STEP:
    STL'ler SLICER'A HAZIR YONDE -- tablaya oturtulmus, ortalanmis.
    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
    [01_namlu.step, 01_namlu.stl, 02_kapsul.step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]
2026-10-01 Gazebo: ozel C++ system plugin ve hibrit devir
    gazebo/plugin/AgFizik.cc -- gz-sim 8 system plugin
    Gazebo'nun kendi surukleme eklentileri ipligi modelleyemiyor; iplik
    gerilmesi (yalnizca cekme) + normal/teget aerodinamik plugin icinde
    hesaplanip AddWorldForce ile uygulaniyor.
    Olculen buyuklukler: ag yaricapi, tepe iplik gerilmesi, kopan eleman,
    hedefe serilme orani, aktarilan momentum, PERVANE DISKINDEN GECEN
    IPLIK SAYISI.
    HIBRIT DEVIR: agin paketten acilmasi rijit-cisim temas problemi degil
    -- paketli halde 709 carpisma kuresi 16 mm hazneye tikili ve DART'in
    LCP cozucusu cokuyor. Cozum: paketten acilma dogrulanmis Python
    modelinde, temas/yakalama Gazebo'da; ag t=80 ms'de acik devraliniyor.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
    [ag_atis.sdf]
2026-10-01 Dokumantasyon: uretim rehberi, tedarik ve sonuc belgeleri
    ALISVERIS.md alisverise giderken tasinacak TEK dosya;
    siparise gore gruplu, 42 kutucuk, ara toplamlar
    URETIM_MONTAJ_REHBERI.md 14 bolum: guvenlik, 3D baski, ag orme (sablon,
    sargi bagi, lacing, katlama), bant hazirlama,
    mekanizma montaji, kurma, yer testleri T1-T6
    malzeme_listesi.md teknik ozellikler, her parcanin nereye gittigi
    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
    [malzeme_listesi.csv, pareto.csv, sobol.csv]
2026-10-02 Servo: MG996R -> MIKRO servo (-82 g, sistem 492 -> 410 g)
    Servo secimi IS KORUNUMUNU gozden kacirarak yapilmisti:
    tork x aci = F_pim x strok = SABIT
    r=4 mm makara servonun donus araliginin yalnizca 86 derecesini
    kullaniyordu. Iki degisiklikle 130 derece kullaniliyor:
    - makara r = 4.0 -> 2.2 mm
    - kapsul tutma kanali derinligi 5 -> 4 mm (strok 6 -> 5 mm)
    Gereken tork: 3.9 -> 2.15 kg.cm
    Sonuc: 2 x MG996R (110 g, 11 kg.cm) yerine 2 x MIKRO metal disli servo
    (Savox SH-0255MG / MG92B sinifi, 14 g, 3.9 kg.cm) -> PAY 1.81x.
    Sistem kutlesi 492 -> 410 g (%17 azalma).
    Yan faydalar:
    - stall akimi 2.5 -> 0.9 A/servo; Y-kablo/BEC yuku hafifledi
    - kanal temas gerilmesi 24 -> 30 MPa, PETG'de SF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
    [01_namlu.step, 01_namlu.stl, 02_kapsul.step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]
2026-10-02 Namlu 180.5 -> 149.8 mm (strok 114 -> 91), sistem 390 g
    Menzil kaybi beklenenden AZ: cikis hizindan %10 verildi ama pencerenin
    uzak kenari yalnizca 26 cm kisaldi.
    namlu strok enerji v_cikis pencere
    180.5mm 114mm 78.2 J 34.6 m/s 3.58-6.80 m
    149.8mm 91mm 62.4 J 31.1 m/s 3.56-6.54 m <- SECILEN
    140.0mm 84mm 57.3 J 29.9 m/s 3.56-6.46 m
    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
    [01_namlu.step, 01_namlu.stl, 02_kapsul.step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]
2026-10-02 Entegrasyon: monte edilebilir model paketi + harici tetikleme
    Simdiye kadar sadece URETILMIS TEST DUNYASI (ag_atis.sdf) vardi; baska
    bir araca takilabilir bir model yoktu. Eklendi:
    1) MODEL PAKETI gazebo/models/ag_firlatici/
    model.config + model.sdf + meshes/ (baski STL'lerinden)
    Eksen: +X namlu ekseni, orijin namlunun ARKA yuzu.
    4 link, gercek kutle ve GERCEK GEOMETRIDEN atalet:
    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
    [ag_atis.sdf, kapsul.stl, model.sdf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]
2026-10-02 Entegrasyon duzeltmeleri: IKI PARCA uyarisi + 3 gercek hata
    Kullanici "arkadasin entegre edecegi modelde sadece ag modellemesi yok mu"
    diye sordu. Dogrulandi: model paketinde 0 plugin, 0 ag dugumu var.
    Sadece <include> yapilirsa DOGRU KUTLELI AMA ATES ETMEYEN bir namlu
    elde ediliyor. Bu, en sik yapilacak hata.
    1) YAPISTIRILABILIR PARCA URETILIYOR
    gazebo/worlds/ag_eklentisi.sdf -- yalnizca ag dugumleri + AgFizik
    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
    [ag_eklentisi.sdf]
2026-10-02 Entegrasyon risk analizi: 2 sessiz hata bulundu ve duzeltildi
    Kullanici "arkadas entegre ederken hata cikma ihtimali var mi" diye
    sordu. Tahmin yerine senaryolar KURULUP KOSULDU. Iki sessiz hata cikti.
    --- HATA 1: ag dugum pozlari MUTLAK yaziliydi (DUZELTILDI) ---
    Dugum pozlari SDF'te mutlak koordinattir ve uretim anindaki varsayilan
    firlatici pozunu (-0.1498, 0, 2.0) temel alir. Kullanici firlaticiyi
    kendi dronunun altina koydugunda -- ki koyacak -- ag ondan KOPUK, yanlis
    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
    [ag_atis.sdf, ag_eklentisi.sdf]
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2026-10-03 Barutlu dal cikarildi: yalnizca ESNEK BANT tahriki
    Kullanici istegi: barut tamamen silinsin, sistem bu sohbetteki haline
    donsun, tahrik yalnizca lateks bant olsun.
    YAPILAN
    * Barutlu calisma ana daldan cikarildi. Kaybolmasin diye etiketlendi:
    git tag arsiv/barutlu-denemesi (7e7136a)
    Geri istenirse: git checkout arsiv/barutlu-denemesi
    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
    [01_namlu.step, 02_kapsul.step, 03_tetik_kapagi_sag.step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]
2026-10-03 Baski: DESTEK ayari duzeltildi (ilk baskida namlu deligi doldu)
    Kullanici 01_namlu.stl'yi bastirdi ve delik ICI DOLU, yuzeyler bozuk
    cikti. Teshis icin STL olculdu:
    STL SAGLAM:
    su gecirmez (tum kenarlar tam 2 ucgende), hacim 154.55 cm3
    (CAD 154.57), delik z=2..148 arasi HER kesitte acik (O42-45).
    Dis geometri fotograflarla birebir ortusuyor (tetik gobekleri,
    servo yataklari, kulaklardaki ankraj delikleri).
    => Fotograftaki ic duvar MODELDE YOK, DESTEK MALZEMESIDIR.
    IKI BELGE HATASI (benim):
    1. "destek: YOK" YANLISTI. STL'den olculdu: yuzeyin %2.4'u (1397 mm2)
    45 dereceden dik asagi bakiyor ve destek ister --
    tetik gobekleri (O18 YATAY silindir, z~133) ve servo yataklari
    (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
    [01_namlu.step, 02_kapsul.step, 03_tetik_kapagi_sag.step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]
2026-10-03 Namlu IKI PARCA + eldeki malzemelerle revize analizi
    1) NAMLU IKI PARCAYA BOLUNDU (cad: namlu_bol)
    Kullanici: "bas kismin havada kalmasi ve altina destek atilmasi"
    sorunu. Agiz basligi (bilezik + O104 kulaklar) ayrildi.
    01a_namlu_govde 122.0 cm3 O55.4 x 142 mm
    01b_agiz_basligi 32.0 cm3 O104 x 21.8 mm
    Birlesim: O49.4 x 14 mm spigot + omuz (494 mm2) + 3x M3 radyal vida.
    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
    [01_namlu.step, 01_namlu.stl, 01a_namlu_govde.step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]
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2026-10-03 v9: Ø9/4g boncuklara göre komple revizyon + menzil hesabı
    Boncuk yeniden ölçüldü: Captain 1216, Ø9 mm, 4 g, ortası delikli.
    Ø9 kurşun + Ø2 delik = 4.01 g ile tutarlı (önceki Ø8 ölçümü hatalıydı).
    NİHAİ TASARIM
    - Ağ Ø2.2 m, kare göz 220 mm, tek ip (0.60 mm) — göz + çevre halatı
    + 40 radyal bağ. 39.2 m ağda, 47.2 m kesim (elde 90 m).
    - 12 × Ø9 boncuk (48 g), yuva başına 2, 6 yuva, eğim 30°.
    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
    [01a_namlu_govde.step, 01a_namlu_govde.stl, 01b_agiz_basligi.step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]
2026-10-03 Baskı/Gazebo dosyaları v9 ile senkronlandı + 3 bozuk üretici düzeltildi
    - cad/v4_hacim.json'ı HİÇBİR betik yazmıyordu (eski bir sürümden kalma
    öksüz dosyaydı) → malzeme_listesi.py kütleleri eski CAD'den okuyordu.
    Artık lastik_montaj_v4.py yazıyor. BOM baskı kütlesi 204.5 → 192.1 g.
    - gazebo/scripts/model_paketi_uret.py namlu bölündüğünden beri bozuktu:
    artık var olmayan baski/01_namlu.stl'yi kopyalıyordu. Mesh'ler artık
    gazebo/scripts/mesh_uret.py ile doğrudan CAD'den üretiliyor (yeni betik);
    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
    [01a_namlu_govde.step, 01b_agiz_basligi.step, 02_kapsul.step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]
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
